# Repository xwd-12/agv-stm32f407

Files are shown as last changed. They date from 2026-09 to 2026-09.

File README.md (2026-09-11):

# STM32F407 AGV 智能搬运机器人

> 2026 全国大学生嵌入式芯片与系统设计竞赛 ST 赛道参赛作品

本项目以 STM32F407ZGTx 为主控，构建四轮差速移动底盘、4-DOF 机械臂、独立挂钩舵机与 OpenMV H7 Plus 视觉系统。它将巡线、二维码触发、端侧视觉识别、颜色对准抓取、AprilTag 视觉伺服和无动力从车拖挂串成一套自主搬运流程。

完整任务链路为：巡线行驶 -> 十字路口触发 -> AprilTag 对接从车 -> QR 触发工位任务 -> 视觉识别与抓取 -> 从车装载或交付。

> 当前默认烧录配置用于工位演示：程序假定从车已预先挂接，并从巡线和工位任务开始执行。完整自动对接功能保留在工程中，需恢复经过实车标定的完整构建配置后再启用。

## 目录

- [功能概览](#功能概览)
- [完整作业流程](#完整作业流程)
- [硬件与软件架构](#硬件与软件架构)
- [视觉任务](#视觉任务)
- [构建与部署](#构建与部署)
- [串口调试](#串口调试)
- [目录结构](#目录结构)
- [安全说明](#安全说明)

## 功能概览

| 能力 | 已实现内容 |
| --- | --- |
| 自主巡线 | 5 路红外巡线、PID 转向、十字路口识别与路线切换 |
| 从车对接 | AprilTag 搜索、视觉伺服倒车、挂钩动作与回归巡线 |
| 视觉搬运 | QR 任务触发、AI 分类、颜色目标对准、抓取与放置 |
| 机械臂控制 | 4-DOF 机械臂动作组、独立挂钩舵机、五次样条平滑运动 |
| 实时控制 | TIM6 100 Hz 控制心跳，巡线、视觉伺服和机械臂状态协同运行 |
| 调试与调参 | UART5 指令调试、OpenMV 数据查看、可选 CSV 遥测与 LLM PID Tuner |

## 完整作业流程

```mermaid
flowchart TD
    A[上电巡线] --> B[十字检测]
    B --> C[AprilTag 对接]
    C --> D[挂接从车]
    D --> E[工位零]
    E --> F[三件抓取]
    F --> G[工位一]
    G --> H[取件交付]
    H --> I[完成停车]
```

完整流程中，车辆先在十字路口进入从车对接阶段，再由 AprilTag 提供相对位姿信息完成视觉引导。挂接后，二维码触发工位任务；系统按红色六边形、黄色长方形、绿色圆形的顺序处理目标，并在两个工位完成装载与交付。

当前 `User/main.c` 的默认配置以工位调试为目的，启用 `SKIP_DOCK=1`，从车应在上电前完成手动挂接。自动对接状态机及其现场参数仍保留在工程内，但当前处于调试禁用状态。复现全流程前应恢复已验证的完整配置、检查场地与标记尺寸，并重新烧录后实车测试；不要仅修改一个宏后直接上车运行。

## 硬件与软件架构

### 硬件组成

| 子系统 | 配置 |
| --- | --- |
| 主控 | STM32F407ZGTx，主频 168 MHz |
| 移动底盘 | 四轮差速底盘，直流减速电机与 PWM 驱动 |
| 机械执行 | 4-DOF 机械臂，腰座、大臂、小臂、夹爪与独立挂钩舵机 |
| 视觉 | OpenMV Cam H7 Plus，支持 QR、AprilTag、颜色识别与端侧分类 |
| 巡线传感 | 5 路红外巡线传感器 |
| 调试通信 | UART5，115200 8N1，USB-TTL 连接 |
| 视觉通信 | USART3，115200，与 OpenMV 专用连接 |

完整引脚映射、外设初始化和中断优先级见 [ARCHITECTURE.md](ARCHITECTURE.md)。

### 软件分层

| 层级 | 主要文件 | 职责 |
| --- | --- | --- |
| 实时控制 | `Timer.c`、`pid.c`、`line_follow.c`、`visual_servo.c` | 100 Hz 控制心跳、巡线 PID、位置/速度控制、视觉伺服 |
| 任务编排 | `main.c`、`state_machine.c`、`vision_task.c` | 从车对接、QR 任务、机械臂状态管理与多步骤任务队列 |
| 视觉通信 | `commend_openmv.c`、`OpenMV_scripts/main.py` | USART3 环形缓冲、视觉数据协议与相机模式切换 |
| 机械执行 | `action_group.c`、`servo.c`、`smooth_servo.c` | 抓取、放置、挂钩及平滑舵机轨迹 |
| 调试接口 | `uart.c`、`command.c` | UART5 命令解析、状态查询与遥测控制 |

系统由 7 个协作状态机组织自主任务，包括机械臂、视觉伺服、视觉任务、任务队列、传统导航、QR 任务流水线和从车对接状态机。

## 视觉任务

OpenMV 在 QR、AprilTag、颜色和 AI 分类模式之间切换，通过 USART3 向主控发送识别结果。二维码负责触发任务，AI 分类确定目标类别，颜色追踪用于末端对准，AprilTag 用于从车对接。

| class_id | 标签 | 颜色目标 |
| :---: | --- | --- |
| 0 | `red_hexagon` | 红色六边形 |
| 1 | `green_circle` | 绿色圆形 |
| 2 | `yellow_rect` | 黄色长方形 |

`OpenMV_scripts/train_mid_f32.py` 可训练并导出当前相机脚本使用的 Float32 MobileNetV2 模型 `model_mid_f32.tflite`。模型文件不随仓库提供；部署时必须使用与 `main.py` 和 `labels.txt` 匹配的模型与标签文件。

## 构建与部署

### STM32 固件

开发环境为 Keil MDK-ARM V5.06 与 ARM Compiler 5。工程使用 C90 语法，新写的局部变量应在代码块开头声明。

1. 打开 `Project/RVMDK（uv5）/SICV_F407.uvprojx`。
2. 选择目标 `AGV`，确认芯片为 STM32F407ZGTx。
3. 按 `F7` 编译。
4. 通过 ST-Link 的 SWD 接口（PA13/PA14）连接开发板，按 `F8` 下载。
5. 编译产物位于 `Output/LED.axf` 和 `Output/LED.hex`。

`keilkill.bat` 会清理构建产物；运行后必须重新执行 `F7`，再执行 `F8` 下载。新增 `User/` 下的 `.c` 或 `.h` 文件后，还需要在 Keil 的 Project Items 中手动加入工程。

### OpenMV 部署

1. 通过 USB 连接 OpenMV H7 Plus。Windows 下通常会挂载为 `H:` 盘。
2. 将 `OpenMV_scripts/main.py`、`OpenMV_scripts/labels.txt` 和匹配的 `model_mid_f32.tflite` 复制到相机内部 Flash 根目录。
3. 相机启动后默认进入 QR 模式；STM32 会根据任务切换 QR、AI、COLOR 或 APRILTAG 模式。

若需要重新训练模型，请在具备 TensorFlow 环境的电脑中进入 `OpenMV_scripts/`，运行 `train_mid_f32.py`，再将导出的模型和标签部署到相机。

### PID Tuner（可选）

配套调参工具位于 `llm-pid-tuner-dev/`。先将根目录的 `config.example.json` 复制为 `config.json`，填入自己的接口配置；真实配置文件已被 Git 忽略，不应提交到仓库。具体运行方式见 [llm-pid-tuner-dev/README.md](llm-pid-tuner-dev/README.md)。

## 串口调试

调试串口为 UART5（PC12/PD2，115200 8N1）。启动后的前 3 秒内，命令会执行但不回显，用于抑制 USB-TTL 上电噪声。

| 命令 | 用途 |
| --- | --- |
| `help` | 查看完整命令列表 |
| `run` / `restart` | 重置自主任务流程并返回巡线 |
| `flow` | 查看整条任务链路的当前状态 |
| `crossdock <0|1>` | 开关十字路口自动对接触发 |
| `dockstat` | 查看从车对接状态 |
| `vpid` | 查看视觉伺服参数与对准状态 |
| `vmode <mode>` | 切换 OpenMV 视觉模式 |
| `vdata` / `vcls` | 查看最新视觉目标或分类结果 |
| `mode <0|1|2|3>` | 切换手动、巡线、位置或视觉伺服模式 |
| `stop` | 紧急停车并切换为手动模式 |

## 目录结构

```text
.
├── User/                         # STM32 应用层源码
│   ├── main.c                    # 主循环、任务流程与对接编排
│   ├── line_follow.c/h           # 巡线控制
│   ├── visual_servo.c/h          # AprilTag 视觉伺服
│   ├── state_machine.c/h         # 机械臂与任务状态机
│   ├── command.c/h               # 串口命令解析
│   └── commend_openmv.c/h        # OpenMV 通信协议
├── OpenMV_scripts/               # 相机脚本、训练脚本、标签与数据集
├── Project/RVMDK（uv5）/          # Keil 工程
├── Libraries/                    # CMSIS 与 STM32 标准外设库
├── llm-pid-tuner-dev/            # 可选 PID 自动调参工具
├── Output/                       # Keil 构建产物
├── ARCHITECTURE.md                # 完整硬件与软件架构参考
└── READY.md                       # 实机调试记录与待办
```

## 安全说明

- 首次烧录或更改运动、视觉、机械臂参数后，应先将车辆架空或在可控场地单独验证，再进行整流程演示。
- `stop`、低压制动、机械臂动作超时和视觉目标丢失保护用于降低风险，但不能替代现场监护。
- 公开仓库仅提供 `config.example.json`；请自行创建本地 `config.json`，并妥善保管 API Key、设备端模型和本机串口配置。

## 参考文档

- [ARCHITECTURE.md](ARCHITECTURE.md)：硬件引脚、控制链路、通信协议和状态机细节。
- [READY.md](READY.md)：实机调试记录、从车对接参数和后续计划。
- [llm-pid-tuner-dev/README.md](llm-pid-tuner-dev/README.md)：PID Tuner 的安装与使用说明。

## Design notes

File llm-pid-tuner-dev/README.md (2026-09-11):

# LLM-PID-Tuner

一个用大语言模型辅助 PID 调参的实用工具。

> 💬 QQ 1群：1082281492 - 欢迎加入交流讨论
> 📺 [B站教程视频](https://b23.tv/WVUuIFb) - 详细视频教程手把手教你使用
> 📺 [YouTube 教程视频](https://youtu.be/Giruc9kN53Y)

中文 | [English](https://github.com/KINGSTON-115/llm-pid-tuner/blob/dev/docs/en-US/README.md)

Star History Chart (https://star-history.com/#KINGSTON-115/llm-pid-tuner)

> 如果你是第一次接触这个项目，**不要先折腾 Python**。
> **最省事的用法是直接下载 Release 里的 `llm-pid-tuner.exe`。**

## 最新开发版教程入口

如果你想看 **最新功能、最新教程、最新 Simulink 配置说明**，请直接参考 `dev` 分支文档：

- [最新总览（中文）](https://github.com/KINGSTON-115/llm-pid-tuner/blob/dev/README.md) | [最新总览（ENGLISH）](https://github.com/KINGSTON-115/llm-pid-tuner/blob/dev/docs/en-US/README.md)
- [最新 Simulink 指南（中文）](https://github.com/KINGSTON-115/llm-pid-tuner/blob/dev/docs/zh-CN/MATLAB_GUIDE.md) | [最新 Simulink 指南（ENGLISH）](https://github.com/KINGSTON-115/llm-pid-tuner/blob/dev/docs/en-US/MATLAB_GUIDE.md)
- [最新项目说明（中文）](https://github.com/KINGSTON-115/llm-pid-tuner/blob/dev/docs/zh-CN/PROJECT_DOC.md) | [最新项目说明（ENGLISH）](https://github.com/KINGSTON-115/llm-pid-tuner/blob/dev/docs/en-US/PROJECT_DOC.md)

如果你只想使用 **当前稳定版 main**，继续阅读本页即可。

## 目录

- [系统结构图](#系统结构图)
- [先看你该怎么用](#先看你该怎么用)
- [这个项目适合什么场景](#这个项目适合什么场景)
- [它不是做什么的](#它不是做什么的)
- [3 分钟上手：Windows 打包版（推荐给小白）](#3-分钟上手windows-打包版推荐给小白)
- [config.json 怎么填](#configjson-怎么填)
- [推荐模型与接口填写方式](#推荐模型与接口填写方式)
- [如何自定义提示词 (Prompt)](#如何自定义提示词-prompt)
- [MATLAB/Simulink 仿真模式](#matlabsimulink-仿真模式)
- [如果你还没有硬件，先跑仿真](#如果你还没有硬件先跑仿真)
- [进阶：源码方式运行](#进阶源码方式运行)

## 系统结构图

```text
┌──────────────────────── 本地仿真模式 (Simulator) ────────────────────────┐
│                                                                         │
│  simulator.py  ───────────── API(JSON) ─────────────>  LLM / AI Tuner   │
│  (热系统仿真)                                           (生成 PID 建议)   │
│                                                                         │
└─────────────────────────────────────────────────────────────────────────┘

┌──────────────────────── 真实硬件模式 (Hardware) ─────────────────────────┐
│                                                                         │
│  MCU / firmware.cpp ── Serial(CSV) ──> tuner.py ── API ──> LLM          │
│  (Arduino / ESP32)                    (上位机 / .exe)                    │
│                                                                         │
└─────────────────────────────────────────────────────────────────────────┘
```

## 先看你该怎么用

- **只想调硬件，不想配开发环境**：走 `exe` 路线，见下方“3 分钟上手”。
- **想先看看这个项目到底有没有用**：运行 `simulator.py` 做本地热系统仿真。
- **想接自己的 Arduino / ESP32 / 其他控制板**：使用 `firmware.cpp` + `tuner.py` / `llm-pid-tuner.exe`。
- **想二次开发或看内部设计**：看 [PROJECT_DOC.md](docs/zh-CN/PROJECT_DOC.md)。

## 这个项目适合什么场景

- 恒温控制：加热板、热端、恒温箱、水浴、烘箱
- 电机 / 执行器：需要 PID 闭环调节的对象
- 已经能跑，但参数不好：响应慢、超调大、抖动、稳态误差明显
- 没有成熟整定经验，希望让 LLM 先帮你缩小试错范围

## 它不是做什么的

- 它**不是**“一键保证完美控制”的魔法程序
- 它**不是**替代硬件保护的安全系统
- 它**不是**为了漂亮 benchmark 分数而设计的玩具

这个项目更在意的是：**真实调参时少走弯路、少炸参数、调差了还能回退。**

---

## 3 分钟上手：Windows 打包版（推荐给小白）

### 第 1 步：下载打包版

打开 [Release](https://github.com/KINGSTON-115/llm-pid-tuner/releases/latest) 页面，并下载资产里的 `llm-pid-tuner.exe`。

### 第 2 步：准备硬件

你需要一个能通过串口持续上报控制数据的板子。

最简单的方式是直接参考仓库里的 `firmware.cpp`，它已经实现了这个项目默认使用的串口协议。

程序默认希望设备通过串口持续输出类似下面的 CSV 数据：

```text
timestamp_ms,setpoint,input,pwm,error,p,i,d
```

如果你不想自己适配协议，**最省事的办法就是直接从 `firmware.cpp` 开始。**

如果你要对接这些已知协议格式，可以在 `config.json` 里明确指定 `HARDWARE_PROFILE`：

- `generic_serial_csv`：默认 CSV 串口数据，适合 `firmware.cpp` 和演示模式
- `stm32f407_openmv`：STM32F407 + OpenMV 瞄准链路，支持 `Status:` 文本、`T:x,y` 和 `N`
- `mspm0_datavision`：MSPM0 DataVision 采样链路，当前是只读遥测模式，不向硬件写回 PID 参数

### 第 3 步：第一次运行 exe

双击运行 `llm-pid-tuner.exe`。

启动器会先让你选择模式：`[1]` 真实硬件调参，`[2]` 本地仿真 TUI（默认）。
如果你现在是准备接串口硬件，请先选 `[1]`。

第一次运行时，如果当前目录下没有 `config.json`，程序会自动生成一份默认配置。

### 第 4 步：填写 `config.json`

打开 `config.json`，至少先把“硬件模式最小必填项”改掉：

```json
{
  "SERIAL_PORT": "AUTO",
  "BAUD_RATE": 115200,
  "HARDWARE_PROFILE": "generic_serial_csv",
  "LLM_API_KEY": "sk-your-key",
  "LLM_API_BASE_URL": "https://api.openai.com/v1",
  "LLM_MODEL_NAME": "gpt-4o",
  "LLM_PROVIDER": "openai"
}
```

如果你只是想先跑 `simulator.py` 看效果，没有接真实串口，也可以先不填 `SERIAL_PORT`，只把 LLM 相关字段填好。

如果你要用 **MiniMax / DeepSeek / Ollama / LM Studio** 这类 OpenAI 兼容接口，通常这样配就行：

```json
{
  "LLM_API_KEY": "你的 key",
  "LLM_API_BASE_URL": "你的 /v1 地址",
  "LLM_MODEL_NAME": "你的模型名",
  "LLM_PROVIDER": "openai"
}
```

比如 MiniMax 兼容接口可以是：

```json
{
  "LLM_API_BASE_URL": "http://你的地址/v1",
  "LLM_MODEL_NAME": "MiniMax-M2.5",
  "LLM_PROVIDER": "openai"
}
```

如果你用的是 **Claude 中转站 / OneAPI / New API 这类 OpenAI 兼容接口**，现在也可以更明确地写成：

```json
{
  "LLM_API_BASE_URL": "https://你的中转站/v1",
  "LLM_MODEL_NAME": "claude-3-7-sonnet",
  "LLM_PROVIDER": "openai_claude"
}
```

`openai_claude` 和 `openai` 都会走 OpenAI 兼容协议；前者只是专门给 Claude 中转站准备的显式选项。

如果你使用 Claude 原生接口，再把 `LLM_PROVIDER` 改成 `anthropic`。

### 第 5 步：重新运行 exe

保存 `config.json` 后重新运行程序。

- 如果 `SERIAL_PORT` 填的是 `AUTO`，程序会扫描串口并让你选择
- 如果你已经知道端口号，比如 `COM5`，也可以直接写死，省掉选择步骤

### 第 6 步：观察调参结果

程序会持续：

- 读取串口数据
- 分析当前响应质量
- 请求 LLM 给出新的 PID 建议
- 必要时使用保底策略
- 如果后续结果变差，会回退到之前更稳的参数
- 当系统“已经够好”时，会尽量提前停止，避免过调

当一轮评测同时满足 `GOOD_ENOUGH_AVG_ERROR`、`GOOD_ENOUGH_STEADY_STATE_ERROR` 和 `GOOD_ENOUGH_OVERSHOOT` 时，程序会保持当前 PID 参数进入观察轮，而不是继续请求 LLM 改参数。连续 `REQUIRED_STABLE_ROUNDS` 轮评测都稳定后停止，默认是 3 轮；如果观察过程中响应变差，稳定计数会清零并恢复正常调参。

你最终需要做的事通常只有一件：**把收敛后的 PID 参数写回你的固件。**

---

## `config.json` 怎么填

第一次运行 `tuner.py`、`simulator.py` 或 `llm-pid-tuner.exe` 时，如果当前目录没有 `config.json`，程序会自动生成一份默认配置。

如果你喜欢先看模板，也可以直接参考仓库里的 `config.example.json`。

### 先改这些就能跑起来

**1. 真实硬件模式最小必填**

```json
{
  "SERIAL_PORT": "AUTO",
  "BAUD_RATE": 115200,
  "HARDWARE_PROFILE": "generic_serial_csv",
  "LLM_API_KEY": "sk-your-key",
  "LLM_API_BASE_URL": "https://api.openai.com/v1",
  "LLM_MODEL_NAME": "gpt-4o",
  "LLM_PROVIDER": "openai"
}
```

**2. 本地 Python 仿真最小必填**

```json
{
  "LLM_API_KEY": "sk-your-key",
  "LLM_API_BASE_URL": "https://api.openai.com/v1",
  "LLM_MODEL_NAME": "gpt-4o",
  "LLM_PROVIDER": "openai"
}
```

**3. Simulink 模式额外补这几项**

```json
{
  "MATLAB_MODEL_PATH": "C:/models/my_pid_model.slx",
  "MATLAB_PID_BLOCK_PATH": "my_pid_model/PID Controller",
  "MATLAB_ROOT": "D:/Program Files/MATLAB/R2025b",
  "MATLAB_OUTPUT_SIGNAL": "y_out",
  "MATLAB_SIM_STEP_TIME": 15.0,
  "MATLAB_SETPOINT": 200.0
}
```

这 6 项是跑通单控制器模型的**最小必填**。

如果你的 Simulink 模型不是“单个标准 PID Controller 块 + 一个输出信号”这种最简单结构（例如主副环、分离式 P/I/D 增益块），程序也支持更复杂的兼容字段。

> **请直接查看完整的 [MATLAB/Simulink 调参指南](docs/zh-CN/MATLAB_GUIDE.md)**。
> 指南里详细说明了：
> - 如何快速获取正确的 Simulink 块路径
> - 如何配置双控制器与分离式增益块
> - `MATLAB_ROOT` 什么时候可以不填
> - 常见环境报错（如 `No module named matlab.engine`）的解决方法

### 按场景看配置项

| 分类 | 什么时候需要 | 字段 | 说明 |
| :--- | :--- | :--- | :--- |
| 硬件串口 | 真实硬件调参 | `SERIAL_PORT` `BAUD_RATE` `HARDWARE_PROFILE` | `SERIAL_PORT` 不确定先填 `AUTO`，`BAUD_RATE` 要和固件一致；普通 CSV 固件保持 `HARDWARE_PROFILE=generic_serial_csv` |
| LLM 基础 | 所有模式都需要 | `LLM_API_KEY` `LLM_API_BASE_URL` `LLM_MODEL_NAME` `LLM_PROVIDER` | 这是最核心的一组配置，不填就无法调参 |
| 调参行为 | 想微调策略时再改 | `BUFFER_SIZE` `MIN_ERROR_THRESHOLD` `MAX_TUNING_ROUNDS` `LLM_REQUEST_TIMEOUT` `LLM_DEBUG_OUTPUT` `PID_LIMITS` `PID_MAX_INCREASE_RATIO` `GOOD_ENOUGH_AVG_ERROR` `GOOD_ENOUGH_STEADY_STATE_ERROR` `GOOD_ENOUGH_OVERSHOOT` `REQUIRED_STABLE_ROUNDS` | 新手建议先保持默认，只有在采样不够、网络慢或需要排查日志时再动。`PID_LIMITS` 用于配置 P/I/D 的绝对上下限和默认单轮增幅；程序会把实际限幅写入 LLM 提示词，并在下发前强制执行。`PID_MAX_INCREASE_RATIO` 是额外的全局单轮增幅上限；`GOOD_ENOUGH_*` 定义“已经够好”的阈值；`REQUIRED_STABLE_ROUNDS` 是连续稳定轮数，默认 3 轮。 |
| Simulink | 只在 MATLAB/Simulink 模式下需要 | `MATLAB_MODEL_PATH` `MATLAB_PID_BLOCK_PATH` `MATLAB_ROOT` `MATLAB_OUTPUT_SIGNAL` `MATLAB_SIM_STEP_TIME` `MATLAB_SETPOINT`，以及按需填写 `MATLAB_CONTROL_SIGNAL` `MATLAB_SETPOINT_BLOCK` `MATLAB_PID_BLOCK_PATHS` `MATLAB_PID_BLOCK_PATH_2` `MATLAB_P/I/D_BLOCK_PATH(_2)` | 最小 6 项先跑通，复杂模型再逐步补充兼容字段 |
| 代理 | 只有需要代理时才填 | `HTTP_PROXY` `HTTPS_PROXY` `ALL_PROXY` `NO_PROXY` | 留空就是不启用 |

> 硬件模式还带有内建的采样保护阈值（采样超时与最少有效样本数）。这些属于固定安全策略，目前不作为 `config.json` 的用户配置项开放。

### `MATLAB_ROOT` 什么时候要填

见 [MATLAB/Simulink 调参指南](docs/zh-CN/MATLAB_GUIDE.md)。

### 关于环境变量

程序也支持环境变量，并且**环境变量优先级高于 `config.json`**。

例如：

```powershell
$env:LLM_API_KEY="sk-xxx"
$env:LLM_API_BASE_URL="http://127.0.0.1:11434/v1"
$env:LLM_MODEL_NAME="qwen2.5:7b"
$env:LLM_PROVIDER="openai"
```

如果你是小白，**优先用 `config.json`，更直观。**

### 关于代理（可选）

如果你需要走 VPN/代理，可以在 `config.json` 里新增以下字段：

```json
{
  "HTTP_PROXY": "http://127.0.0.1:7890",
  "HTTPS_PROXY": "http://127.0.0.1:7890",
  "ALL_PROXY": "http://127.0.0.1:7890",
  "NO_PROXY": ""
}
```

留空则**不启用代理**，对不需要代理的用户没有影响。

### 导出 CSV 数据（可选）

如果你希望将调参过程中的实时数据（时间戳、设定值、当前值、PWM、误差、PID参数等）保存下来，以便后续在 Excel 或 MATLAB 中分析，可以在 `config.json` 中配置 `CSV_EXPORT_PATH` 字段：

```json
{
  "CSV_EXPORT_PATH": "logs/tuning_data.csv"
}
```

- 填入你希望保存的 CSV 文件路径（支持相对路径或绝对路径）。
- 每次运行调参时，程序会自动将数据追加到该文件中，并记录当前的 `session_id` 和 `round`（轮次），方便你区分不同次的调参记录。
- 留空（`""`）则**不导出 CSV**。

---

## 推荐模型与接口填写方式

| 方案 | `LLM_API_BASE_URL` 示例 | `LLM_PROVIDER`  | 说明 |
| :--- | :--- | :--- | :--- |
| OpenAI | `https://api.openai.com/v1` | `openai` | 最省心 |
| DeepSeek 兼容接口 | 对应服务商的 `/v1` 地址 | `openai` | 常见且便宜 |
| MiniMax 兼容接口 | 对应服务商的 `/v1` 地址 | `openai` | 推理能力适合调参 |
| Claude 中转站 / OneAPI / New API | 对应服务商的 `/v1` 地址 | `openai_claude` | Claude 模型走 OpenAI 兼容协议时用这个最直观 |
| Ollama | `http://localhost:11434/v1` | `openai` | 本地免费部署 |
| LM Studio | `http://localhost:1234/v1`  | `openai` | 本地可视化较友好 |
| Anthropic Claude | `https://api.anthropic.com` | `anthropic` | 原生接口用这个 |

这个项目现在做了更稳的解析和回退处理，**对 OpenAI 兼容接口更友好**。如果 SDK 路径不顺，它也会尽量走更直接的 HTTP 路径，减少“能调通 API 但程序不工作”的情况。

---

## 如何自定义提示词 (Prompt)

本项目提供了两种自定义提示词（调参策略）的方式，以适应不同的需求：

### 1. 预调参对话（推荐，无需改代码）
在每次启动调参（无论是仿真还是硬件模式）时，程序会首先进入**预调参对话 (Pre-Tuning Conversation)**。
在这里，你可以直接用自然语言输入你的偏好。例如：
- *"我希望系统绝对稳定，不能有任何超调，哪怕响应慢一点也没关系。"*
- *"这是一个对响应速度要求极高的系统，允许 10% 以内的超调，请尽可能激进地调参。"*
- *"注意，这个电机的死区比较大，P 参数可以给大一点。"*

程序会自动将你的自然语言偏好转化为结构化的 JSON 约束，并附加到 LLM 的系统提示词中，从而改变 LLM 的调参行为。

### 2. 修改源码中的系统提示词（进阶）
如果你希望永久改变 LLM 的核心调参逻辑或角色设定，你需要修改源码：
1. 打开 `llm/prompts.py` 文件。
2. 找到 `_BASE_SYSTEM_PROMPT` 变量，这里定义了 LLM 的核心角色、职责和调参原则。
3. 找到 `_MODE_NOTES` 变量，这里定义了不同模式（如 `hardware`, `simulink`, `python_sim`）下的特定规则。
4. 根据你的需求修改这些字符串内容即可。

---

## MATLAB/Simulink 仿真模式

如果你已经有 MATLAB/Simulink 仿真模型，可以直接让 LLM 对你的模型进行 PID 调参，无需真实硬件。

在 `config.json` 里至少填写下面这些字段，再运行 `python simulator.py` 或打包版启动器里的 Simulink 模式：

- `MATLAB_MODEL_PATH`：Simulink `.slx` 文件路径
- `MATLAB_PID_BLOCK_PATH`：模型里的 PID 模块完整路径
- `MATLAB_OUTPUT_SIGNAL`：To Workspace 输出变量名
- `MATLAB_ROOT`：MATLAB 安装根目录；打包版建议填写，源码运行如果当前 Python 已装好 MATLAB Engine 可以留空

详细配置步骤、模型准备方法和常见问题，见 [MATLAB/Simulink 调参指南](docs/zh-CN/MATLAB_GUIDE.md)。

---

## 如果你还没有硬件，先跑仿真

如果你只是想确认这个项目到底在干什么，先跑这个：

```bash
pip install -r requirements.txt
python simulator.py
```

`simulator.py` 会在本地模拟一个热系统，然后让 LLM 自动调参。
这条路线最适合先理解项目，而不是直接上真实硬件。

在调参循环开始前，程序现在会自动进行两个对新手非常友好的操作：
- 运行环境诊断（`doctor.py`），检查配置、API 连接性、串口及代理设置。
- 进行简短的系统辨识（热启动），给出比默认值更合理的初始 PID 建议。

此外，交互模式下支持**预调参对话**（Pre-Tuning Dialog）。你可以用自然语言直接输入调参偏好或限制（例如：“超调不能超过 5%” 或 “响应可以慢点但绝不能震荡”），LLM 会自动提取为调参的硬性约束。

如果你只想手动运行环境检查而不启动仿真，可以使用：

```bash
python doctor.py
```

---

## 进阶：源码方式运行

如果你不想用 exe，也可以直接跑源码。

### 分支说明（重要）

- `dev` 分支：当前最新开发代码，功能修复、TUI 改动、打包前验证都会先进入这里
- `main` 分支：更偏稳定展示和正式 release，同步会慢一些，不保证是当前最新行为
- 如果你想源码运行、跟进最近修复，或者准备提 PR，建议直接拉 `dev`

### 新拉仓库：直接拉 `dev`

```bash
git clone -b dev https://github.com/KINGSTON-115/llm-pid-tuner.git
cd llm-pid-tuner
```

### 你已经拉过仓库：切到 `dev` 并更新

```bash
git fetch origin
git checkout dev
git pull --ff-only origin dev
```

### 安装依赖

```bash
pip install -r requirements.txt
```

如果你要跑 Simulink 源码模式，还需要让当前这个 Python 环境能导入 `matlab.engine`。不会配的话，直接看 [MATLAB/Simulink 调参指南](docs/zh-CN/MATLAB_GUIDE.md)。

### 运行前先确认配置

- 跑 `python tuner.py`：至少填好 LLM 配置和串口配置
- 跑 `python simulator.py`：至少填好 LLM 配置
- 跑 Simulink：再额外补 `MATLAB_*` 相关字段

第一次运行时如果没有 `config.json`，程序会自动生成一份默认配置；你也可以直接从 `config.example.json` 开始改。

### 运行仿真

```bash
python simulator.py
```

如果你想用旧式纯日志输出，而不是 TUI，或者需要强制切换显示语言：

```bash
python simulator.py --plain
python simulator.py --lang en  # 强制使用英文界面，默认支持根据系统自动检测语言
```

### 连接真实硬件

```bash
python tuner.py
```

### 做系统辨识（可选）

你可以先采一段阶跃响应数据，再用 `system_id.py` 给出一组初值建议：

```bash
python system_id.py --file sample_step.csv
```

这适合想先拿到一组“不会太离谱”的初始参数，再交给 LLM 继续细调的用户。

---

## 主要文件是干什么的

| 文件 | 用途 |
| :--- | :--- |
| `launcher.py` | 启动器，可选择硬件或仿真模式并支持语言切换 |
| `tuner.py` | 真实硬件调参主程序，也是 exe 的核心入口 |
| `simulator.py` | 本地热系统仿真，适合演示和验证策略 |
| `pid_safety.py` | 参数保护、保底策略、最佳结果记录、回退逻辑 |
| `firmware.cpp` | 单片机侧示例固件，负责串口上报与执行 PID |
| `system_id.py` | 利用阶跃响应做系统辨识，给出初始 PID 建议  |
| `doctor.py` | 环境诊断检查工具，快速排查配置与连接问题 |
| `benchmark.py` | 固定随机种子的对比工具，更偏开发验证用途 |
| `config.json` | 运行配置文件 |
| `docs/zh-CN/PROJECT_DOC.md` | 面向开发者的内部说明文档 |

---

## 常见问题

### 1）双击 exe 后一闪而过

常见原因：

- `config.json` 还没填好
- API Key 无效
- 串口打不开
- 当前目录没有写入权限，导致配置文件生成失败

建议直接在 PowerShell 里运行，这样错误信息不会消失：

```powershell
.\llm-pid-tuner.exe
```

### 2）程序找不到串口

检查下面几件事：

- 设备是否真的连上电脑
- 驱动是否安装正确
- 其他上位机是否已经占用了串口
- `BAUD_RATE` 是否和单片机一致

### 3）程序连上了，但一直没有数据

大概率是你的固件输出格式和项目默认协议不一致。
最稳妥的办法是先按 `firmware.cpp` 的格式对齐。

### 4）LLM 能聊天，但程序调不动

多数时候是这几类问题：

- `LLM_API_BASE_URL` 写错
- 模型名写错
- 你用的是 OpenAI 兼容接口，但 `LLM_PROVIDER` 填成了 `anthropic`
- 你用的是 Claude 中转站，但把它当成了 Anthropic 原生接口；这时应该用 `openai_claude` 或 `openai`
- 服务端虽然可用，但返回 JSON 风格不稳定

### 5）调着调着结果变差怎么办

现在的程序会：

- 给 PID 做基本护栏限制
- LLM 异常时启用保底建议
- 记录历史最佳稳定参数
- 后续结果明显变差时自动回退

也就是说，它的设计目标不是“每一轮都更激进”，而是**优先把系统留在一个更稳、更可用的位置。**

### 6）能不能完全离线使用

可以，但前提是你本地起了兼容 OpenAI 接口的模型服务，比如：

- Ollama
- LM Studio

然后把 `LLM_API_BASE_URL` 指向本地地址即可。

---

## 安全提醒

**在真实硬件上调参时，请务必有人值守。**

尤其是加热类系统，一定要有：

- 硬件级限温
- 传感器异常保护
- 继电器 / MOS 管失控保护
- 必要时的物理断电手段

这个项目能帮你减少调参痛苦，但**不能替代硬件安全设计**。

---

## 补充说明

- 最新打包版请看 [Release](https://github.com/KINGSTON-115/llm-pid-tuner/releases/latest)
- 打包方法见 [Issue #11](https://github.com/KINGSTON-115/llm-pid-tuner/issues/11)
- 当前 Windows 打包使用 Python `3.10` 环境（本项目测试使用 `matlab310` conda 环境），`llm-pid-tuner.spec` 会从当前环境收集必要 DLL
- 历史测试环境包含 `R2022b`；文档里的 `R2025b` 只是示例路径版本，请替换成你本机实际安装的 MATLAB 版本
- 想看项目内部设计，请看 [PROJECT_DOC.md](docs/zh-CN/PROJECT_DOC.md)

## License

`CC BY-NC-SA 4.0`

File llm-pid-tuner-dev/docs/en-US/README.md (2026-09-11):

# LLM-PID-Tuner

An LLM-assisted PID tuning tool focused on reducing the painful trial-and-error process of real controller tuning.

[中文](../../README.md) | English

Star History Chart (https://star-history.com/#KINGSTON-115/llm-pid-tuner)

> 📺 [Video Tutorial (Bilibili)](https://b23.tv/WVUuIFb)
> 📺 [YouTube Tutorial](https://youtu.be/Giruc9kN53Y)

> New here? The easiest path is **not** Python.
> Download the packaged `llm-pid-tuner.exe` from Releases and start there.

## Table of Contents

- [System Architecture](#system-architecture)
- [Best starting path](#best-starting-path)
- [3-minute quick start for beginners](#3-minute-quick-start-for-beginners)
- [How to fill config.json](#how-to-fill-configjson)
- [How to customize prompts](#how-to-customize-prompts)
- [MATLAB/Simulink Simulation Mode](#matlabsimulink-simulation-mode)
- [If you don't have hardware yet, run the simulator](#if-you-dont-have-hardware-yet-run-the-simulator)
- [Advanced: Running from source](#advanced-running-from-source)

## System Architecture

```text
┌──────────────────────── Local Simulation Mode ──────────────────────────┐
│                                                                         │
│  simulator.py  ───────────── API(JSON) ─────────────>  LLM / AI Tuner   │
│  (thermal model)                                        (PID decisions) │
│                                                                         │
└─────────────────────────────────────────────────────────────────────────┘

┌──────────────────────── Real Hardware Mode ─────────────────────────────┐
│                                                                         │
│  MCU / firmware.cpp ── Serial(CSV) ──> tuner.py ── API ──> LLM          │
│  (Arduino / ESP32)                    (host app / exe)                  │
│                                                                         │
└─────────────────────────────────────────────────────────────────────────┘
```

## Best starting path

- **Just want to tune hardware**: use the packaged `exe`
- **Want to see the idea first**: run `simulator.py`
- **Want to integrate your own board**: use `firmware.cpp` + `tuner.py`
- **Want internals**: read [PROJECT_DOC.md](PROJECT_DOC.md)

---

## 3-minute quick start for beginners

### 1. Download the packaged app

Open [Latest Release](https://github.com/KINGSTON-115/llm-pid-tuner/releases/latest) page and download `llm-pid-tuner.exe` from the Assets section.

### 2. Prepare hardware

Your board should stream CSV data over serial.

The easiest route is to start from `firmware.cpp`, which already matches the protocol expected by this project.

Expected CSV format:

```text
timestamp_ms,setpoint,input,pwm,error,p,i,d
```

If you use one of the built-in hardware profile adapters, set `HARDWARE_PROFILE` explicitly in `config.json`:

- `generic_serial_csv`: default CSV serial telemetry, suitable for `firmware.cpp` and demo mode
- `stm32f407_openmv`: STM32F407 + OpenMV aiming/targeting telemetry, including `Status:` snapshots, `T:x,y`, and `N`
- `mspm0_datavision`: MSPM0 DataVision telemetry, currently read-only and does not write PID values back to hardware

If you omit this field, the app uses `generic_serial_csv`.

### 3. Run the exe once

Double-click `llm-pid-tuner.exe`.

The launcher now asks which mode to start:
`[1]` hardware tuning or `[2]` the local simulation TUI (default).
If you are connecting a real serial device, choose `[1]`.

If `config.json` does not exist, the program generates a default one automatically.

### 4. Edit `config.json`

At minimum, start with the hardware-mode fields below:

```json
{
  "SERIAL_PORT": "AUTO",
  "BAUD_RATE": 115200,
  "HARDWARE_PROFILE": "generic_serial_csv",
  "LLM_API_KEY": "sk-your-key",
  "LLM_API_BASE_URL": "https://api.openai.com/v1",
  "LLM_MODEL_NAME": "gpt-4o",
  "LLM_PROVIDER": "openai"
}
```

If you only want to try `simulator.py` first and are not connecting real hardware yet, you can leave `SERIAL_PORT` unset and just fill the LLM fields.

For OpenAI-compatible providers such as MiniMax, DeepSeek, Ollama, or LM Studio, keep `LLM_PROVIDER` as `openai` and point `LLM_API_BASE_URL` to the provider's `/v1` endpoint.

Example:

```json
{
  "LLM_API_BASE_URL": "http://your-endpoint/v1",
  "LLM_MODEL_NAME": "MiniMax-M2.5",
  "LLM_PROVIDER": "openai"
}
```

If you use Claude through an OpenAI-compatible relay such as OneAPI or New API, you can now make that explicit:

```json
{
  "LLM_API_BASE_URL": "https://your-relay.example.com/v1",
  "LLM_MODEL_NAME": "claude-3-7-sonnet",
  "LLM_PROVIDER": "openai_claude"
}
```

Both `openai` and `openai_claude` use the OpenAI-compatible transport. `openai_claude` is just the clearer choice for Claude relays.

For native Claude APIs, use `LLM_PROVIDER: "anthropic"`.

### 5. Run it again

- If `SERIAL_PORT` is `AUTO`, the app scans ports and lets you choose
- If you already know the port, set something like `COM5`

### 6. Watch the tuning loop

The app will:

- collect serial data
- evaluate response quality
- ask the LLM for new PID values
- fall back to safer suggestions when needed
- remember the best stable result
- roll back when a later suggestion clearly makes things worse
- stop early when the system is already “good enough”

When one evaluation round satisfies `GOOD_ENOUGH_AVG_ERROR`, `GOOD_ENOUGH_STEADY_STATE_ERROR`, and `GOOD_ENOUGH_OVERSHOOT`, the app keeps the current PID values and enters observation rounds instead of asking the LLM for another adjustment. It stops after `REQUIRED_STABLE_ROUNDS` consecutive stable evaluations, which defaults to 3; if the response gets worse during observation, the stable counter resets and normal LLM tuning resumes.

In practice, this means the tool tries to be useful on real hardware, not just aggressive.

---

## How to fill `config.json`

On the first run of `tuner.py`, `simulator.py`, or `llm-pid-tuner.exe`, the app generates a default `config.json` automatically if one does not exist.

If you prefer starting from a template, check `config.example.json`.

### Start with these fields

**1. Minimum config for real hardware**

```json
{
  "SERIAL_PORT": "AUTO",
  "BAUD_RATE": 115200,
  "HARDWARE_PROFILE": "generic_serial_csv",
  "LLM_API_KEY": "sk-your-key",
  "LLM_API_BASE_URL": "https://api.openai.com/v1",
  "LLM_MODEL_NAME": "gpt-4o",
  "LLM_PROVIDER": "openai"
}
```

**2. Minimum config for the built-in Python simulator**

```json
{
  "LLM_API_KEY": "sk-your-key",
  "LLM_API_BASE_URL": "https://api.openai.com/v1",
  "LLM_MODEL_NAME": "gpt-4o",
  "LLM_PROVIDER": "openai"
}
```

**3. Extra fields for Simulink mode**

```json
{
  "MATLAB_MODEL_PATH": "C:/models/my_pid_model.slx",
  "MATLAB_PID_BLOCK_PATH": "my_pid_model/PID Controller",
  "MATLAB_ROOT": "D:/Program Files/MATLAB/R2025b",
  "MATLAB_OUTPUT_SIGNAL": "y_out",
  "MATLAB_SIM_STEP_TIME": 15.0,
  "MATLAB_SETPOINT": 200.0
}
```

Those six fields are the **minimum setup** for a single-controller model.

If your Simulink model is not the simplest "single standard PID Controller block + one output signal" layout (e.g., dual-loop, split P/I/D gain blocks), the tool also supports advanced compatibility fields.

> **Please refer directly to the full [MATLAB/Simulink Tuning Guide](docs/en-US/MATLAB_GUIDE.md)**.
> The guide covers:
> - How to find exact Simulink block paths easily
> - How to configure dual controllers and split gain blocks
> - When `MATLAB_ROOT` is actually required
> - How to troubleshoot environment errors (e.g., `No module named matlab.engine`)

### Config groups by use case

| Group | When needed | Fields | Notes |
| :---- | :--- | :----- | :---- |
| Serial hardware | Real hardware tuning | `SERIAL_PORT` `BAUD_RATE` `HARDWARE_PROFILE` | Start with `SERIAL_PORT: "AUTO"` and match the firmware baud rate. Keep `HARDWARE_PROFILE=generic_serial_csv` for regular CSV firmware |
| LLM basics | Required in every mode | `LLM_API_KEY` `LLM_API_BASE_URL` `LLM_MODEL_NAME` `LLM_PROVIDER` | This is the core set needed for any tuning run |
| Tuning behavior | Optional | `BUFFER_SIZE` `MIN_ERROR_THRESHOLD` `MAX_TUNING_ROUNDS` `LLM_REQUEST_TIMEOUT` `LLM_DEBUG_OUTPUT` `PID_LIMITS` `PID_MAX_INCREASE_RATIO` `GOOD_ENOUGH_AVG_ERROR` `GOOD_ENOUGH_STEADY_STATE_ERROR` `GOOD_ENOUGH_OVERSHOOT` `REQUIRED_STABLE_ROUNDS` | Leave defaults unless you are tuning strategy or debugging. `PID_LIMITS` configures absolute P/I/D bounds and default per-round increase ratios; the app injects the active limits into the LLM prompt and enforces them before write-back. `PID_MAX_INCREASE_RATIO` is an extra global cap for one adjustment. `GOOD_ENOUGH_*` defines the "good enough" thresholds, and `REQUIRED_STABLE_ROUNDS` is the number of consecutive stable evaluations before stopping. The default is 3. |
| Simulink | MATLAB/Simulink mode only | `MATLAB_MODEL_PATH` `MATLAB_PID_BLOCK_PATH` `MATLAB_ROOT` `MATLAB_OUTPUT_SIGNAL` `MATLAB_SIM_STEP_TIME` `MATLAB_SETPOINT`, plus optional `MATLAB_CONTROL_SIGNAL` `MATLAB_SETPOINT_BLOCK` `MATLAB_PID_BLOCK_PATHS` `MATLAB_PID_BLOCK_PATH_2` `MATLAB_P/I/D_BLOCK_PATH(_2)` | Start with the minimum six fields, then add compatibility fields only when needed |
| Proxy | Only if you need one | `HTTP_PROXY` `HTTPS_PROXY` `ALL_PROXY` `NO_PROXY` | Leave empty to disable |

> Hardware mode also includes built-in sampling guardrails such as a serial sampling timeout and a minimum valid-sample threshold. These are fixed safety defaults and are not exposed as `config.json` user settings right now.

### When should I fill `MATLAB_ROOT`?

See the [MATLAB/Simulink Tuning Guide](docs/en-US/MATLAB_GUIDE.md).

Environment variables are also supported and override `config.json`, but beginners usually find `config.json` easier.

### Proxy (optional)

If you need a VPN/proxy, add these fields to `config.json`:

```json
{
  "HTTP_PROXY": "http://127.0.0.1:7890",
  "HTTPS_PROXY": "http://127.0.0.1:7890",
  "ALL_PROXY": "http://127.0.0.1:7890",
  "NO_PROXY": ""
}
```

Leave them empty to **disable proxy**. If you do not need a proxy, you can ignore these fields.

### Export CSV Data (optional)

If you want to save real-time data during the tuning process (timestamp, setpoint, input, PWM, error, PID parameters, etc.) for later analysis in Excel or MATLAB, you can configure the `CSV_EXPORT_PATH` field in `config.json`:

```json
{
  "CSV_EXPORT_PATH": "logs/tuning_data.csv"
}
```

- Fill in the path where you want to save the CSV file (supports relative or absolute paths).
- Every time you run the tuner, the program will automatically append data to this file and record the current `session_id` and `round`, making it easy to distinguish between different tuning sessions.
- Leave it empty (`""`) to **disable CSV export**.

---

## Recommended providers

| Provider | `LLM_API_BASE_URL` example  | `LLM_PROVIDER`  |
| :--- | :--- | :--- |
| OpenAI | `https://api.openai.com/v1` | `openai` |
| MiniMax-compatible | provider `/v1` URL | `openai` |
| DeepSeek-compatible | provider `/v1` URL | `openai` |
| Claude relay / OneAPI / New API | provider `/v1` URL | `openai_claude` |
| Ollama | `http://localhost:11434/v1` | `openai` |
| LM Studio | `http://localhost:1234/v1`  | `openai` |
| Anthropic Claude | `https://api.anthropic.com` | `anthropic` |

The current runtime is hardened for OpenAI-compatible endpoints and includes a more direct HTTP fallback path when SDK behavior is not enough.

---

## How to customize prompts

This project provides two ways to customize prompts (tuning strategies) to suit different needs:

### 1. Pre-Tuning Conversation (Recommended, no coding required)
Every time you start tuning (whether in simulation or hardware mode), the program will first enter the **Pre-Tuning Conversation**.
Here, you can directly input your preferences in natural language. For example:
- *"I want the system to be absolutely stable with zero overshoot, even if the response is a bit slow."*
- *"This is a system that requires extremely fast response. Overshoot within 10% is acceptable. Please tune as aggressively as possible."*
- *"Note that this motor has a large deadband, so the P parameter can be larger."*

The program will automatically convert your natural language preferences into structured JSON constraints and append them to the LLM's system prompt, thereby changing the LLM's tuning behavior.

### 2. Modify the system prompt in source code (Advanced)
If you want to permanently change the core tuning logic or role setting of the LLM, you need to modify the source code:
1. Open the `llm/prompts.py` file.
2. Find the `_BASE_SYSTEM_PROMPT` variable, which defines the core role, responsibilities, and tuning principles of the LLM.
3. Find the `_MODE_NOTES` variable, which defines specific rules for different modes (e.g., `hardware`, `simulink`, `python_sim`).
4. Modify these string contents according to your needs.

---

## MATLAB/Simulink simulation mode

If you already have a MATLAB/Simulink model, you can tune its PID parameters directly with LLM assistance — no real hardware needed.

Set these fields in `config.json`, then run `python simulator.py` or choose the Simulink mode from the packaged launcher:

- `MATLAB_MODEL_PATH`: path to the Simulink `.slx` file
- `MATLAB_PID_BLOCK_PATH`: full path to the PID block inside the model
- `MATLAB_OUTPUT_SIGNAL`: To Workspace variable name
- `MATLAB_ROOT`: MATLAB install root; recommended for the packaged app, optional for source runs when `matlab.engine` already imports in your Python environment

For full setup instructions, model requirements, and troubleshooting, see the [MATLAB/Simulink Tuning Guide](docs/en-US/MATLAB_GUIDE.md).

---

## No hardware yet? Run the simulator first

```bash
pip install -r requirements.txt
python simulator.py
```

`simulator.py` models a simple local heating system and opens a lightweight Textual terminal dashboard by default when run in an interactive terminal.

Before the tuning loop starts, it now does three beginner-friendly things automatically:

- runs a quick doctor check for config, API reachability, serial ports, expected protocol fields, and proxy settings
- runs a short system-identification warm start so the initial PID is better than the fixed default values
- supports a **Pre-Tuning Conversation** (Interactive mode only), where you can describe tuning preferences and hard constraints in natural language (e.g., "overshoot must be less than 5%"), which the LLM will automatically enforce.

- Press `q` to quit the dashboard
- Press `p` to pause or resume the simulation loop
- Press `l` to toggle concise vs detailed event logs
- Press `r` to clear the event log and temporary summary

If you prefer the old plain log output, or want to explicitly set the language:

```bash
python simulator.py --plain
python simulator.py --lang zh  # Override language to Chinese. The system auto-detects English/Chinese by default.
```

If the current terminal is non-interactive, or if `textual` is not installed yet, the simulator falls back to plain console logs automatically.

If you want to run the startup checks manually without launching the simulator, use:

```bash
python doctor.py
```

---

## Run from source

If you want the latest behavior from source, prefer `dev` over `main`. New fixes, TUI changes, and pre-release validation land on `dev` first, while `main` is the slower-moving stable branch.

### Fresh clone: use `dev`

```bash
git clone -b dev https://github.com/KINGSTON-115/llm-pid-tuner.git
cd llm-pid-tuner
```

### Existing clone: switch to `dev` and update

```bash
git fetch origin
git checkout dev
git pull --ff-only origin dev
```

### Install dependencies

```bash
pip install -r requirements.txt
```

If you plan to run Simulink from source, make sure this same Python environment can import `matlab.engine`. The [MATLAB/Simulink Tuning Guide](docs/en-US/MATLAB_GUIDE.md) covers that setup.

### Before you run

- `python tuner.py`: fill LLM settings and serial settings
- `python simulator.py`: fill LLM settings
- Simulink mode: also fill the `MATLAB_*` fields

If `config.json` does not exist yet, the program will create a default one on first run. You can also start from `config.example.json`.

### Common commands

- `python tuner.py`

- `python simulator.py`
- `python simulator.py --plain`
- `python doctor.py`
- `python system_id.py --file sample_step.csv`
- `python benchmark.py --cases baseline fallback llm --rounds 8`

---

## Main files

| File | Purpose |
| :--- | :--- |
| `launcher.py` | Packaged exe entry that routes to hardware or simulation |
| `tuner.py` | Main hardware tuning runtime |
| `simulator.py` | Local thermal simulation |
| `pid_safety.py` | Guardrails, fallback logic, best-result tracking, rollback |
| `firmware.cpp` | Example MCU firmware |
| `system_id.py` | Step-response based system identification |
| `doctor.py` | Environment check utility to debug config/API issues |
| `benchmark.py` | Fixed-seed comparison utility |
| `docs/en-US/PROJECT_DOC.md` | Developer-oriented project notes |

---

## FAQ

### The exe closes immediately

Common reasons:

- `config.json` is incomplete
- invalid API key
- serial port cannot be opened
- current directory is not writable

Run it from PowerShell to keep the error message visible:

```powershell
.\llm-pid-tuner.exe
```

### The app cannot find my serial port

Check:

- cable / driver
- whether another tool already opened the port
- whether your baud rate matches the firmware

### I get a connection but no useful data

Usually the board is not sending the expected CSV protocol. Start from `firmware.cpp` if possible.

### Can I use it fully offline?

Yes, if you run a local model server such as Ollama or LM Studio and expose an OpenAI-compatible endpoint.

---

## Safety

**Always supervise real hardware during tuning.**

Especially for heating systems, you still need hardware-level protection such as:

- over-temperature cutoff
- sensor failure handling
- power-stage fault protection
- physical power disconnect if necessary

This tool reduces tuning pain. It does not replace hardware safety design.

## License

`CC BY-NC-SA 4.0`

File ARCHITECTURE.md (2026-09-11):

# ARCHITECTURE.md

STM32F407 AGV firmware — 完整架构参考文档。按需查阅，不随每次会话自动加载。

> **提示**：在日常编码中不需要逐页阅读本文。遇到以下情况时查阅对应章节：
> -   修改 GPIO / 外设 / 中断 → §1 Hardware Pins → §2 ISR
> -   修改循迹控制 → §3 Line-Follow
> -   修改视觉/OpenMV → §4 OpenMV → §5 Visual Servo → §6 Vision → §7 AI Pipeline
> -   修改机械臂动作 → §11.3 Servo Power → §11.4 ArmSM
> -   修改串口/CSV → §9 CSV Protocol
> -   调试启动 → §12 Startup → §13 Main Loop
> -   定位 Bug → §15 Bug Tracking

---

## 1. Hardware Pin Mapping (Full)

### DC Motors (4 differential-drive wheels, left/right pairs)

| ID | Name | PWM (Timer) | IN1 | IN2 |
|----|---|---|-----|-----|
| 0 | 左前 | PA7 (TIM3_CH2) | PE3 | PE4 |
| 1 | 右前 | PA6 (TIM3_CH1) | PE5 | PE6 |
| 2 | 左后 | PB1 (TIM3_CH4) | PC8 | PC4 |
| 3 | 右后 | PB15 (TIM12_CH2) | PD3 | PD4 |

Motor PWM: **1kHz** (ARR=999, PSC=83, 84MHz base), duty 0–999.
Speed range: ±1000 (mapped to duty via `speed * 999 / 1000`).

### Servos (4-DOF arm)

| User ID | Joint | PWM (Timer) | Angle range |
|---|---|---|---|
| 0 | 腰座 (waist) | PA8 (TIM1_CH1) | 0–180° |
| 1 | 大臂 (shoulder) | PA9 (TIM1_CH2) | 0–180° |
| 2 | 小臂 (elbow) | PA2 (TIM9_CH1) | 0–180° |
| 3 | 夹爪 (gripper) | PA11 (TIM1_CH4) | 0–180° |

Servo PWM: 50Hz (ARR=19999, PSC=167, 168MHz base), pulse 500–2500.
Note: `pwm.h` defines both `SERVO_ELBOW` (TIM1_CH3/PA10, unused zombie channel) and `SERVO_ELBOW_PA2` (TIM9_CH1/PA2, active). The elbow was remapped from PA10 to PA2 but the old define remains.

### Quadrature Encoders

| ID | Timer | CH1 | CH2 |
|----|---|-----|-----|
| 0 (左前) | TIM5 | PA0 | PA1 |
| 1 (右前) | TIM2 | PA15 | PB3 |
| 2 (左后) | TIM4 | PB6 | PB7 |
| 3 (右后) | TIM8 | PC6 | PC7 |

### Communication & Sensors

| Interface | Peripheral | Pins | Notes |
|---|---|---|---|
| Debug UART | UART5 (115200) | PC12(TX), PD2(RX) | Primary command + CSV telemetry |
| Bluetooth | USART2 (9600) | PD5(TX), PD6(RX) | **Currently disabled** — implemented in `hc_sr40.c/h` (misnamed, NOT ultrasonic). `BT_Init()` commented out, ISR `#if 0`'d. USART2 cannot coexist with UART5 at current NVIC priorities (both would need prio 0,0 to beat TIM6) |
| Line sensor ×5 | GPIO input | PC0, PC1, PC2, PC3, PA4 | Active-low, pull-up, weighted error |
| OLED | I2C | (see `OLEDIIC.c`) | Currently disconnected |
| OpenMV | USART3 (115200) | PC10(TX), PC11(RX) | Camera vision data (`$TAG` packets) |
| CountSensor | EXTI1 on PB1 | PB1 | External interrupt counter; ISR exists but body is empty — hardware is wired but unused |

---

## 2. ISR Priority Layout (Full)

NVIC priorities (lower number = higher priority; preemption priority, subpriority format):

| ISR | Peripheral | File | Priority (pre,sub) | Role |
|-----|---|---|---|---|
| `PVD_IRQHandler` | PVD | `Timer.c` | 0,0 | Brownout: immediate motor brake |
| `UART5_IRQHandler` | UART5 | `uart.c` | 0,0 | Debug UART RX ring buffer (tied with PVD as highest) |
| `TIM6_DAC_IRQHandler` | TIM6 | `Timer.c` | 1,0 | 100Hz control heartbeat |
| `USART2_IRQHandler` | USART2 | `hc_sr40.c` | 2,0 | Bluetooth RX **(disabled via `#if 0`)** |
| `USART3_IRQHandler` | USART3 | `commend_openmv.c` | 2,0 | OpenMV camera RX ring buffer |
| `EXTI1_IRQHandler` | EXTI1 | `CountSensor.c` | 3,3 | Counter input **(empty handler)** |

**Key implication**: UART5 at prio 0,0 can preempt TIM6 (prio 1,0). During heavy CSV telemetry, UART5 ISR steals cycles from the 100Hz control loop. USART2 (BT) is disabled because it would need prio 0,0 to not lose data at 9600 baud, but that conflicts with UART5. If BT is re-enabled, the NVIC priorities must be rebalanced.

---

## 3. Control System Design (Detailed)

**Timer interrupt**: TIM6 fires at **100Hz (10ms)** — the central control heartbeat (`User/Timer.c:TIM6_DAC_IRQHandler`).

**Four operating modes** (`work_mode`):
- `MODE_MANUAL (0)` — Serial commands directly set `target_speed[]`
- `MODE_LINE_FOLLOW (1)` — Line sensor PID → `target_speed[]` per 10ms. Supports timed stop via `line_time_ticks`: when `line_time_ticks > 0 && g_sys_tick >= line_time_ticks`, motors are stopped and mode switches to MANUAL. The `line_time <sec>` serial command sets this (argument in seconds, internally converted to absolute tick).
- `MODE_POSITION (2)` — Position PID outer loop → `target_speed[]` per 20ms
- `MODE_VISUAL_SERVO (3)` — OpenMV vision-guided approach (`#define MODE_VISUAL_SERVO 3` at `visual_servo.h:7`; fully wired into the TIM6 ISR dispatch at `Timer.c:95`)

**Nested PID loops**:
1. **Position loop** (20ms, positional PID `pid_positon[]`): Target position → speed command (±600)
2. **Speed loop** (10ms, incremental PID `pid_motor[]`): Speed command → motor PWM output (±1000)
3. **Line-follow loop** (10ms, positional PID in `line_follow`): Sensor error → turn correction → modifies `target_speed[]`

### 3.1 Line-Follow PID

**Line sensor array** (`User/line_sensor.h`): 5-channel IR on PC0–PC3 + PA4. GPIO reads compared `!= 0` so `states[i]==1` means line detected (header says active-low). Weighted error `{-2,-1,0,1,2}` normalized by detection count → error ±2.

**Line-follow PID** (`User/line_follow.c`): Features sensor debounce (3-sample majority vote in `LineSensor_Read`), deadband on error (±0.1 → zeroed), EMA on derivative (70% old + 30% new), integral separation at ±1.5 error threshold, trapezoidal integration, and turn output clamping at ±600. Output speeds clamped to [0, 1000] (forward-only; inner wheel stops but doesn't reverse on sharp turns). Turn is added to left wheels and subtracted from right wheels (differential steering).

**Line-loss behavior**: When no sensor detects the line, motors coast at 60% of last known speed (±30 min) for 50 ticks (500ms), then integrals zeroed and motors stop. Prevents nuisance stops from brief dropouts.

**Curve detection**: Built-in curve counter (`curve_count`, `curve_target`, `curve_ready` fields in `Line_follow_Handle`). A "curve" is detected when ≤4 of 5 sensors see the line for 3 consecutive frames. After `curve_target` curves + `curve_delay_ms` delay, `curve_ready` is set to 1. This can be used to trigger actions after passing a known number of curves on the track.

**Motor 3 right-rear compensation**: Motor 3 encoder is broken → open-loop control. In line-follow, `right - 20` is applied to motor 3 speed to compensate for its tendency to run faster without encoder feedback. This hardware-specific hack is only in the line-follow path; other modes use `encoder_max[3] = 0` open-loop fallback in the TIM6 ISR.

**Motor direction polarity**: `motor_dir[] = {1, -1, 1, -1}` corrects for motor mounting orientation so positive `target_speed` always means forward.

---

## 4. OpenMV Vision Subsystem

**OpenMV Vision Communication** (`User/commend_openmv.c/h`): USART3 (PC10=TX, PC11=RX, 115200 baud) dedicated to the OpenMV camera. Uses the same ring-buffer ISR + polling pattern as the debug UART. Parses data packets at ~10–50Hz. Three data structures are maintained:

- **`OpenMV_Data`** — AprilTag/color blob tracking: `tag_id`, `cx`, `cy`, `distance_cm`, `angle_deg`, `pixel_width`. Used by visual servo and vision_task.
- **`OpenMV_QRData`** — QR code decoded text (up to 64 chars). Used by the AI auto-scan main-loop pipeline.
- **`OpenMV_CLSData`** — AI classification result: `class_id` (-1=uncertain) and `confidence` (0–100%). Used by the AI auto-scan main-loop pipeline.

All three use a `fresh` flag pattern for ISR-to-main-loop producer-consumer sync. ISR-safe `OpenMV_TagSeenRecently()` queries tag presence by timestamp without consuming data. `OpenMV_PollLine()` drains the ring buffer in the main loop. OpenMV mode is set via `OpenMV_SendCmd("MODE,<mode>")` where mode is `APRILTAG`, `COLOR`, `QRCODE`, or `AI`.

**Serial packet formats** (USART3, 115200 baud):
- `$TAG,<id>,<cx>,<cy>,<dist_cm>,<angle_deg>,<width>` — AprilTag/color blob detection
- `$QR,<payload>` — QR code decoded text
- `$CLS,<class_id>,<confidence>` — AI classification result (class_id=-1 means uncertain)
- `$HB` — Heartbeat (aliveness check via `OpenMV_IsAlive()`)

Commands are sent as `$CMD,<command>\r\n` (e.g. `$CMD,MODE,AI\r\n`).

**OpenMV firmware**: `OpenMV_scripts/main.py` (source backup). The active firmware is on the H7 Plus internal flash (H: drive when USB-connected). Utilities: `train.py`, `capture.py`, `test_*.py`. Models: `model_mid.tflite` (active), `model.tflite`, `model_small.tflite`. Legacy: `vision_main.py` (5-state-machine, not active).

**Model loading**: H7 Plus has 32MB internal flash — no SD card needed. The active model `model_mid.tflite` (~630KB, MobileNetV2 α=0.35 INT8) is loaded via `ml.Model(load_to_fb=True)` from `/flash/`. The model is lazy-loaded on first `MODE,AI` command to avoid blocking startup.

**QR debounce**: QR codes require 3 consecutive frame confirmations; on loss, output is held for 5 frames before clearing. This adds ~150–250ms latency to QR detection/loss transitions.

---

## 5. Visual Servo

**Visual Servo** (`User/visual_servo.c/h`): Implements `MODE_VISUAL_SERVO (3)` — dual PID for autonomous AprilTag docking:
- **Lateral PID**: Steers to center the tag horizontally (target `cx=160`, 320×240 image). Output clamped to ±turn_limit (default 400).
- **Longitudinal PID**: Controls forward/backward speed to reach the target distance. Output clamped to ±base_speed_max (default 150).
- Outputs combined via differential steering: `left = forward + turn`, `right = forward - turn`.
- Features integral separation on both axes, IIR low-pass filter on derivatives (70% new + 30% old), trapezoidal integration, loss-of-tag handling (stops motors after configurable timeout, default 200ms), and hysteresis-based alignment detection (N consecutive frames within tolerances, default 5 frames).
- Follows the same handle-pattern convention as `Line_follow_Handle` — `VisualServo_Task()` is called at 100Hz from the TIM6 ISR.

---

## 6. Vision Task Mission Orchestrator

**Vision Task** (`User/vision_task.c/h`): A high-level, non-blocking state machine that coordinates OpenMV vision data with line-following and arm actions. Three mission types:
- **Color search** (`VIS_COLOR_SEARCH → VIS_COLOR_APPROACH → VIS_COLOR_GRASP → VIS_DONE`): Line-follow until target color blob detected → approach using centroid-based steering → grasp at close range.
- **QR code search** (`VIS_QR_SEARCH → VIS_QR_APPROACH → VIS_QR_EXECUTE → VIS_DONE`): Line-follow until QR code detected → approach → execute decoded command (supports `GRASP` and `PLACE` keywords; defaults to grasp if no command).
- **AI classification scan** (`VIS_AI_SCAN → VIS_AI_APPROACH → VIS_AI_EXECUTE → VIS_DONE`): Stop and classify objects via OpenMV's onboard model → approach detected target → execute action based on class ID.

Each mission type sets the OpenMV mode (`OMV_MODE_COLOR`, `OMV_MODE_QRCODE`, `OMV_MODE_AI`) and switches to line-follow or manual mode as needed. Missions have configurable approach/grasp distance thresholds and 1s target-loss timeout (100 ticks). `VisionTask_Process()` is called from `main()` and throttles to 50ms intervals. State queries via `VisionTask_IsBusy()` / `VisionTask_GetState()`.

---

## 7. Main-Loop AI Pipeline (Primary Autonomous Mission, QR-triggered)

Located inline in `main.c` (`qr_phase` 0–11 state machine, main loop). This is the **active** autonomous mission orchestrator — it replaced the older `#if 0`'d timed auto-mission. **QR 触发**: the pipeline starts by scanning a QR code, approaches to 15cm, then runs AI classification / color alignment / grasp / place. It only activates after docking completes (`dock_state == 5`, `main.c:615`), so it never races the dock state machine. Two stations:

```
Station 0 (抓取放从车): QR 触发 → approach 15cm → 识别(AI 分类, 腰座±20° 扫描) → QuickAlign 色块对准 → 抓取 → 放置到从车(180°) → 下一件
Station 1 (从车取件交付): QR→AI→COLOR 识别从车上物件 → 取件 → 交付
任务序列: mission_idx 0→2, mission_class[] = {0,2,1} (红→黄→绿); 两站跑完 mission_done
关键 phase: 0=QR触发+approach, 1=识别(腰座±20°扫描), 10=QuickAlign 色块对准, 3=抓取,
           11=放置(180°), 7=AprilTag 定位, 9=AI(skip_pick), 8=Station0 下一件, 4/5/6=Station1 取件交付
每阶段独立超时兜底 + `restart`/`run` 一键恢复
```

The pipeline coexists with `VisionTask_Process()` but operates independently. `mission_idx`/`station_idx` are globals (`main.c:94-95`, both start at 0). Lateral alignment uses waist servo rotation + body forward/back; AI classification filters by `mission_class[mission_idx]`.

**class_id → color mapping** (OpenMV model labels → vision_task color IDs):

| class_id | Label | Color ID | OpenMV Mode |
|:--:|---|:--:|---|
| 0 | red_hexagon | 1 (Red) | COLOR |
| 1 | green_circle | 2 (Green) | COLOR |
| 2 | yellow_rect | 3 (Yellow) | COLOR |

---

## 8. TaskQueue System (Mission Sequencer)

`User/state_machine.c/h` defines a **TaskQueue** — a scriptable multi-step mission sequencer (separate from the legacy `TaskNav` and the AI auto-scan pipeline). Up to 16 steps (`TASK_QUEUE_MAX`), each step is a `TaskStep`:

```c
typedef struct {
    uint8_t  travel_mode;    // 0=encoder mileage, 1=line-follow
    int32_t  encoder_dist;   // target encoder counts for this leg
    int16_t  tag_id;         // AprilTag ID for docking (-1 = skip docking)
    int16_t  dock_distance;  // visual servo stop distance (cm)
    uint8_t  action;         // ACTION_GRASP / ACTION_PLACE / ACTION_HOOK / ACTION_UNHOOK / ACTION_NONE
    int16_t  action_param;   // e.g. place waist angle
} TaskStep;
```

TaskQueue state machine: `TQ_TRAVEL → TQ_DOCK → TQ_ACTION → (next step) → TQ_DONE`. During TRAVEL, two triggers can advance to DOCK: (1) encoder mileage reached, or (2) target AprilTag spotted within 100ms (auto-transition to visual servo docking). Per-step timeouts: TRAVEL=30s (3000 ticks), DOCK=10s (1000 ticks), ACTION=8s (800 ticks). Hook/unhook actions (`ACTION_HOOK`/`ACTION_UNHOOK`) call `Action_HookTrailer()`/`Action_UnhookTrailer()` — placeholders for trailer coupling control.

`TaskQueue_Process()` is called from `main()` in the main loop. It is NOT ISR-safe (blocking arm actions use `Delay_ms`).

---

## 9. Debug Interface

Serial commands via **UART5** (wired USB-UART, PC12/PD2) and **Bluetooth USART2** (PD5/PD6, 9600 baud). Both feed into `Commend_Parse()`. `fputc` redirects `printf` to either UART5 or BT based on `uart_set_bt_output()`. Format: `<command> <args>`. Full list via `help` command. Key categories:

- **Motion**: `spd`, `m f|b|l|r|s`, `mode <0-3>`, `stop`, `reset`, `enable <0|1>`, `line_time <sec>`
- **PID tuning**: `kp/ki/kd`, `pos_kp/pos_ki/pos_kd`, `lkp/lki/lkd`, `base_speed`, `PID`, `SET KP:...`, `SETPOINT:`
- **Encoder**: `enc_pos`, `enc_speed`, `enc_max`, `enc_dir`, `enc_clear`, `enc_raw`, `enc_speed_all`, `pid_dbg`
- **Servo**: `servo`, `s_smooth`, `servo_on/off`, `a_set`, `t_set`, `show_act`
- **Arm**: `grasp`, `place <waist>`, `reset_arm`, `show`
- **OpenMV**: `vmode`, `vcolor`, `vtag`, `vqr`, `vfind`, `vqrgo`, `vfind_ai`, `vstop`, `vdata`, `vqrtext`, `vcls`, `vstat`
- **Task**: `task_start`, `task_stop`, `task_status`
- **System**: `save/load` (placeholder), `BT`

---

## 10. CSV Data Protocol & LLM PID Tuner

The main loop sends PID telemetry over UART5 every 50ms (5 `g_sys_tick` units) via `sendPIDDataToUART()` in `User/command.c`. **Currently `sendPIDDataToUART()` is commented out at `main.c:1125` — uncomment it to enable the CSV stream for the LLM PID Tuner.** Each print produces 4 lines (one per motor):

```
<motor_id>,<tick>,<setpoint>,<speed>,<output>,<error>,<Kp>,<Ki>,<Kd>\r\n
```

Note the order: `motor_id` (int) comes first, then `tick` (uint32_t, formatted as `%lu`).

**`llm-pid-tuner-dev/`** is a companion Python project that reads this CSV stream over serial and uses an LLM (OpenAI/Claude/Ollama/etc.) to auto-tune motor PID gains. See its `README.md` for setup. Key files:
- `tuner.py` — real-hardware tuning entry point
- `simulator.py` — local thermal system simulation (no hardware needed)
- `pid_safety.py` — parameter guardrails, rollback to best-known-stable params
- `doctor.py` — environment diagnostics (API connectivity, serial port check)
- `firmware.cpp` — reference Arduino/ESP32 firmware implementing the same CSV protocol

The tuner sends PID updates as serial text commands the existing command parser already handles: `kp/ki/kd <id> <val>` and bulk `SET KP:<p> KI:<i> KD:<d> [M:<id>]`.

---

## 11. Key Architecture Details

### 11.1 Global Tick
`volatile uint32_t g_sys_tick` increments at 100Hz in the TIM6 ISR (`User/Timer.c`). Used by `main()` for periodic tasks (LED heartbeat every ~500k loop iterations, CSV reporting every 5 ticks).

### 11.2 Volatile Shared Variables (ISR ↔ main loop)

These are read/written by both ISR and main-loop code — never assume they stay constant across multiple main-loop statements.

| Variable | Location | Writer | Readers |
|---|---|---|---|
| `g_sys_tick` | `Timer.c` | TIM6 ISR | main loop, line_follow, vision_task |
| `target_speed[4]` | `main.c` | TIM6 ISR (speed PID output), main loop (manual/vision) | TIM6 ISR (PWM output) |
| `work_mode` | `main.c` | main loop (serial cmd) | TIM6 ISR (dispatch) |
| `motor_enable` | `main.c` | main loop, PVD ISR | TIM6 ISR (gates PWM output) |
| `line_time_ticks` | `Timer.c` | main loop (`line_time` cmd) | TIM6 ISR (line-follow stop check) |
| `g_sys_ms` | `DELAY.c` | SysTick ISR (1ms) | `Delay_ms()`, `Delay_Start()` |
| `rx_buf[]/rx_head/rx_tail` | `uart.c` | UART5 ISR (write head) | main loop (read tail) |
| `omv_rx_buf[]/head/tail` | `commend_openmv.c` | USART3 ISR (write head) | main loop (`OpenMV_PollLine()`) |
| `omv_qr_fresh/buf` | `commend_openmv.c` | USART3 ISR | main loop (AI pipeline) |
| `omv_cls_fresh/data` | `commend_openmv.c` | USART3 ISR | main loop (AI pipeline) |
| `omv_ai_ready` | `commend_openmv.c` | USART3 ISR (`$OK,BOOT`) | main loop (AI init wait) |
| `omv_model_error` | `commend_openmv.c` | USART3 ISR (`$ERR`) | main loop (AI error check) |
| `omv_last_hb_tick` | `commend_openmv.c` | USART3 ISR (`$HB`) | main loop (`OpenMV_IsAlive()`) |

**Rule**: In main-loop code, take a local snapshot of any ISR-shared variable you check more than once (e.g. `uint32_t tick = g_sys_tick;` then use `tick`). The compiler may re-read the `volatile` from memory each time, giving inconsistent values.

### 11.3 PID Features
Both position and incremental PID include integral separation (integral zeroed when |error| > threshold), back-calculation anti-windup (stop integrating when output saturated in same direction as error), trapezoidal integration, and a first-order IIR low-pass filter on the derivative term. Default speed PID gains (incremental): motors 0,1 → Kp=5.5 Ki=0.16 Kd=0; motors 2,3 → Kp=5.0 Ki=0.14 Kd=0. Default position PID: Kp=0.5 Ki=0.001 Kd=0. Default line-follow: base_speed=180, Kp=180.0 Ki=2.0 Kd=2.0.

### 11.4 Motor & Encoder Polarity
`motor_dir[] = {1, -1, 1, -1}` and `encoder_dir[] = {-1, -1, -1, -1}` (all-negative default) correct for physical mounting orientation. Sensor data is multiplied by `encoder_dir[i]` before speed PID; speed commands are multiplied by `motor_dir[i]` before PWM output. A positive `target_speed` always means "forward" at the application level.

### 11.5 Hardware Limitations
Motor 3 (右后) encoder is physically broken — `encoder_max[3] = 0` in main.c, which triggers open-loop fallback in the TIM6 ISR (speed command mapped directly to PWM without PID feedback). The OLED display is physically disconnected — `OLED_Init()` is commented out to avoid I2C timeout stalling startup. Navigation encoder averaging in `TaskNav_Process()` and `TaskQueue_Process()` uses only motors 0–2, excluding motor 3.

### 11.6 Smooth Servo
(`User/smooth_servo.c`): Uses quintic (5th-order) polynomial smoothstep interpolation for jerk-limited servo motion. Called from TIM6 ISR at 100Hz. Includes automatic speed limiting — if the requested motion exceeds `MAX_ANGULAR_VEL` (180°/s peak), the duration is automatically extended.

### 11.7 Servo Power Management
(`smooth_servo.c:168-177`): After reaching target position, each servo has custom power-off behavior (reduces heat and power draw): (1) **Shoulder (ID 1) + Elbow (ID 2)** — always stays powered on (holds against gravity); (2) **Waist (ID 0)** — powered off permanently after reaching position; (3) **Gripper (ID 3)** — cycle mode (hold 500ms → off 5s → re-power 500ms → repeat). If modifying servo behavior, check the `HOLD_TICKS`/`OFF_TICKS`/`ON_TICKS` timing constants.

### 11.8 Arm State Machine
(`User/state_machine.h`): Tracks `ArmState` enum (IDLE/GRASPING/PLACING/RESETTING/ESTOP). Action sequences in `action_group.c` check state before executing and reject overlapping commands with "Arm busy". Features 50ms debounce on state transitions (DEBOUNCE_TICKS=5, checked at 100Hz in `ArmSM_Tick10ms()`) and per-operation timeouts via `ArmSM_Tick10ms()` (30s grasp, 30s place, 30s reset → auto-ESTOP). Overlapping requests return 0 (rejected); callers should check `ArmSM_IsBusy()` before requesting.

### 11.9 Legacy AGV Task Navigation
(`User/state_machine.c`): The `TaskNav` state machine executes full autonomous missions: `TASK_IDLE → TASK_GO_TO_A (line-follow to pickup) → TASK_GRASP (arm grasp) → TASK_GO_TO_B (line-follow to delivery) → TASK_PLACE (arm place) → TASK_DONE`. Progress is measured via encoder averaging (motors 0–2 only; motor 3 encoder is broken). `TaskNav_Process()` is called from main loop at ~100Hz but throttles distance checks to 50ms intervals. Arm actions within it are blocking (use `Delay_ms`), which is safe in the main loop but NOT in ISR context. Each travel leg has a 30s timeout.

### 11.10 PVD Brownout Protection
(`User/Timer.c:PVD_Init`): Configures PVD interrupt at 2.9V threshold (PWR_PVDLevel_7). When VDD drops below 2.9V, `PVD_IRQHandler` immediately brakes all motors and sets `motor_enable = 0`. Priority is NVIC priority 0,0 — the highest in the system.

### 11.11 Encoder Safety
(`User/enconder.c`): IIR low-pass filter (70% prev + 30% new) on speed. Fault detection: delta >10× max → 10 consecutive = force-resync. 16-bit counter wraparound handled.

### 11.12 JTAG Release
`Encoder_Init()` remaps PA15/PB3 from JTAG to GPIO_AF_TIM2, keeping only SWD (PA13/PA14). `DBGMCU->CR` trace pins (PE2–PE6) disabled in `main()`.

### 11.13 Stack/Heap Constraints
(from `startup_stm32f40xx.s`): Stack size = **1024 bytes** (`0x400`), Heap size = **512 bytes** (`0x200`). These are very small — avoid deep call stacks, large local arrays, and dynamic allocation (`malloc`/`new`). A stack overflow will silently corrupt `.data` or heap. No MPU is configured to catch overflows. If adding recursive functions, deeply nested calls, or large local buffers (>256 bytes), increase the stack size in the startup file.

### 11.14 Ring Buffer Pattern
Both UART5 (debug) and USART3 (OpenMV) use the same ring-buffer ISR + main-loop polling pattern. ISR pushes bytes into a circular buffer; the main loop drains them with `uart_rb_getchar()` (UART5) or `OpenMV_PollLine()` (OpenMV). During `printf()` bursts, ISR silently captures bytes to prevent data loss. Never poll RXNE directly from the main loop — it races with the ISR.

### 11.15 `__weak` Parameter Hooks
`Save_parameters()` and `Load_parameters()` are declared `__weak` in `command.c`. They're currently empty placeholders but can be overridden in another translation unit to implement persistent PID parameter storage (e.g., in Flash or EEPROM). The `save`/`load` serial commands call these.

### 11.16 Mode Define Duplication
`MODE_MANUAL`/`MODE_LINE_FOLLOW`/`MODE_POSITION` are in both `line_follow.h` and `main.c`; `MODE_VISUAL_SERVO` only in `visual_servo.h`. Check both locations when modifying mode constants.

---

## 12. Startup Sequence

(`User/main.c`):
1. `Motor_EmergencyBrake()` — immediately grounds all motor IN pins before any slow peripheral init (prevents floating-IN startup runaway)
2. SystemInit → SysTick (1ms) → NVIC config → disable DBGMCU trace pins (PE2–PE6)
3. LED_Init → UART5 init → print "a\r\n" (power-on alive signal) → OpenMV USART3 init (Bluetooth `BT_Init()` is commented out — USART2 is currently unused)
4. Motor + PWM init → Delay_ms(200) → Servo + SmoothServo + Arm state machine + Action param init + VisionTask init
5. VisualServo init (any tag, 15cm stop distance, default PID) + TaskQueue init
6. Encoder + line sensor init
7. PID + line-follow init with default gains
8. TIM6 100Hz ISR start + PVD enable
9. All PID states zeroed, `motor_enable = 0`, target_speed[] cleared, motors stopped
10. `motor_enable = 1; work_mode = MODE_LINE_FOLLOW` — auto-enter line-following (上电直接进循迹)
11. `Action_Reset()` → wait for idle → LED blinks 3 times (MCU-alive heartbeat)
12. Enter `while(1)` — serial command processing + AI auto-scan pipeline + periodic tasks

Note: The **timed auto-mission** (grasp at 5s, place at ~22s) is **disabled** via `#if 0` at `main.c:228`. It has been replaced by the AI auto-scan pipeline and the TaskQueue system.

Note: **开跑整流程 (auto-start run flow)** — boot sets `cross_dock_enable=1` (crossroad auto-dock ON) and prints the `AGV RUN FLOW READY` banner; the robot then runs: line-follow → 十字路口(5路全踩) → 右拐脱线对准 → AprilTag 倒车对接挂钩 → Station0(抓3件放从车) → Station1(从车取件交付) → LED 三闪完成. Serial `run`/`restart` performs a full-flow reset (AI pipeline `qr_phase`/mission/station counters + dock state machine + `dock_done_once`), returning to line-following.

Note: `MotorSelfTest()` (sequential ±400 pulse per motor) is defined as a static function in `main.c` but is **not called** in the current startup sequence — it exists for manual debugging if needed.

---

## 13. Main Loop Detail

(`User/main.c`): After init, the robot is already in `MODE_LINE_FOLLOW` — line-following runs autonomously in the TIM6 ISR. The `while(1)` loop handles:
1. UART5 serial command input (ring-buffer drain only — **no direct RXNE polling**; ISR handles all RX to avoid hardware register races)
   - **Startup silent period**: For the first 300 ticks (3s) after entering the main loop, incoming UART chars are parsed silently — no echo, but commands still execute. After 3s, printable ASCII chars are echoed back. This suppresses USB-TTL noise during power-up.
   - **Error filtering**: UART bytes with Frame Error (FE) or Noise Error (NE) flags are silently discarded (by ISR) — prevents garbage from polluting the command buffer during power transients.
   - Ring buffer ISR captures all bytes; main loop drains them via `uart_rb_getchar()`. Direct RXNE polling from main loop would race with the ISR and is explicitly avoided (see `main.c:222-223`).
2. AI pipeline (`qr_phase` 0–11, QR-triggered; gated on `dock_state==5`) + dock 状态机 (`dock_state` 0–7, 从车对接)
3. LED heartbeat (~500k loop iterations per toggle)
4. CSV PID telemetry placeholder (currently commented out)
5. `OpenMV_PollLine()` for vision data ring-buffer drain
6. `TaskNav_Process()` (legacy AGV navigation)
7. `VisionTask_Process()` (color/QR/AI mission orchestrator)
8. `TaskQueue_Process()` (scriptable multi-step mission sequencer)
9. Bluetooth command input via `BT_GetLine()`

UART bytes arriving during `printf()` bursts are captured by ISR into a ring buffer and replayed when the main loop drains it — preventing data loss during CSV telemetry output.

---

## 14. 从车拖挂 + 视觉伺服对接

从车是纯机械拖斗（无电无MCU），前面贴 AprilTag 供对接。设计决策：箱子抓取用巡线+腰座比例转向（±5cm）；从车对接用视觉伺服双PID（需±1cm硬连接精度）。`vision_task.c` 管箱子抓取，`visual_servo.c` 管对接 PID，`main.c` 内联 `dock_state` 0–7 状态机编排整条对接链（十字路口→右转→找码→倒车→挂钩→回轨）。对接流程：巡线到十字路口（5路全踩）→原地右转90°脱线→找 AprilTag ID=1→`VisualServo_TaskReverse` 双PID精确倒车（横向差速转向+纵向线性减速，右后/右前开环补偿）→到位停车挂钩→回轨切回 `MODE_LINE_FOLLOW`。丢码 1s（`miss>100`）刹车回找码；找码 30s 总超时放弃对接恢复巡线。调参见 `READY.md`「从车对接实机验证 (2026-08-24)」。

---

## 15. Bug Tracking (Bug#1–#7)

Active design issues/hazards tagged as `Bug#N` in comments throughout the codebase. These are known limitations, not undiscovered bugs:

| Bug | Description | Location |
|:---|:---|:---|
| **Bug#1** | Phase 2 hard timeout uses a separate timer not reset by frame refreshes | `main.c:287,421,584` |
| **Bug#2** | Cross-task scan state (`nodata_start`, `scan_step`, `scan_tick`) must be manually reset when transitioning tasks | `main.c:288,414,597` |
| **Bug#3** | ArmSM return value must be checked before calling `Action_Grasp()`/`Action_Place()` | `main.c:623`, `state_machine.c:271,322` |
| **Bug#4** | Phase 1 waist servo scans ±20° around center after 2s to increase detection range | `main.c:293,373` |
| **Bug#5** | OpenMV `$ERR` packets are parsed but main-loop error handling is not fully wired | `commend_openmv.c:29,264` |
| **Bug#6** | 50ms delay after OpenMV mode switch prevents stale first-frame data | `main.c:408` |
| **Bug#7** | UART ring-buffer peeking for "stop" during blocking arm actions enables software emergency stop | `action_group.c:63,67` |

When editing code near any Bug# tag, read the surrounding comments for context.

---

## 16. State Machines Summary (7 total)

| State Machine | Location | Context | Trigger | Purpose |
|:---|:---|:---|:---|:---|
| `ArmSM` | `state_machine.c` | TIM6 ISR (10ms tick) | Serial cmd / TaskNav / TaskQueue / QR pipeline | Arm busy/lockout + timeout guard |
| `TaskNav` | `state_machine.c` | main loop (50ms throttle) | `task_start` serial cmd | Legacy 2-leg go-grasp-go-place mission |
| `TaskQueue` | `state_machine.c` | main loop | API call (`TaskQueue_AddStep()` + `TaskQueue_Start()`) | Scriptable N-step mission with visual docking |
| `VisionTask` | `vision_task.c` | main loop (50ms throttle) | `vfind`/`vqrgo`/`vfind_ai` cmd | Color/QR/AI search-approach-execute |
| AI pipeline | `main.c` (inline, `qr_phase` 0–11) | main loop | QR 触发 + `dock_state==5` | QR→AI/color align→grasp/place (Station0/1) |
| dock 状态机 | `main.c` (inline, `dock_state` 0–7) | main loop | 十字路口 5路全踩 / `crossdock` 命令 | 从车对接: 停车→原地右转→找 AprilTag→倒车→挂钩 |
| `VisualServo` | `visual_servo.c` | TIM6 ISR (100Hz) | `work_mode == 3` | Low-level dual-PID docking control |

**Rule**: Any code that calls `Action_Grasp()`/`Action_Place()` must first check `ArmSM_IsBusy()` or use `ArmSM_RequestGrasp()`/`ArmSM_RequestPlace()` which return 0 if the arm is busy. Call `ArmSM_NotifyComplete()` after the action finishes.

---

## 17. Key Tunable Constants

| Constant | File | Default | Purpose |
|---|---|---|---|
| `MAX_ANGULAR_VEL` | `smooth_servo.c` | 180°/s | Servo speed cap |
| `RX_BUF_SIZE` | `uart.c` | 512 | Debug UART ring buffer |
| `OMV_BUF_SIZE` | `commend_openmv.h` | 256 | OpenMV ring buffer |
| `TASK_QUEUE_MAX` | `state_machine.h` | 16 | Max mission steps |
| `TIMEOUT_GRASP/PLACE/RESET` | `state_machine.c` | 3000 ticks (30s) | Arm action timeout |
| `DEBOUNCE_TICKS` | `state_machine.c` | 5 (50ms) | ArmSM state debounce |
| `DEFAULT_APPROACH_DIST` | `vision_task.c` | 15cm | Vision approach trigger |
| `DEFAULT_GRASP_DIST` | `vision_task.c` | 8cm | Vision grasp trigger |
| `DEFAULT_LOST_TIMEOUT` | `vision_task.c` | 100 ticks (1s) | Target loss timeout |
| `APPROACH_BASE_SPEED` | `vision_task.c` | 100 | Vision approach base speed |
| `WAIST_ADJUST_GAIN` | `vision_task.c` | 0.12°/px | Waist steering gain |
| `APPROACH_SPEED_SLOW` | `vision_task.c` | 60 | AI approach slow speed |
| `PID_DEFAULT_DT` | `pid.c` | 0.01 (10ms) | PID sample time |

---

## 18. Karpathy 编码指南

行为准则：编码前思考（明确假设、呈现权衡）、简洁优先（最少代码、不过度推测）、精准修改（只碰必须碰的、匹配现有风格）、目标驱动执行（定义成功标准、循环验证）。详见用户记忆。

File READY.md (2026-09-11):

# AGV 智能搬运机器人 — 开发记录

## 当前状态 (2026-06-23)

### 硬件
- STM32F407 + 4 轮差速驱动 + 4-DOF 机械臂
- OpenMV 摄像头 (USART3, 115200)
- 5 路巡线传感器
- SD 卡 ✅ (已购买, AI 模型已训练部署)

### 已完成
- [x] AI 模型训练 + 部署 (MobileNetV2 α=0.35, int8量化, 三分类)
- [x] QR + AI + 颜色对准 + 抓取 全流程联调
- [x] 三物体依次抓取演示视频录制
- [x] 视觉伺服双 PID 框架 (visual_servo.c, 278行)
- [x] 视觉伺服 PID 串口调参命令 (vkp/vki/vkd/vkp2/vki2/vkd2/vdist/vcx/vpid)
- [x] LLM PID Tuner 框架就绪 (stm32f407_openmv 双控制器 profile)
- [x] 6 状态机全部实现 (ArmSM / TaskNav / TaskQueue / VisionTask / AI pipeline / VisualServo)

### 控制参数
| 参数 | 值 |
|---|-----|
| 巡线 base_speed | 180 |
| 巡线 Kp/Ki/Kd | 180 / 2.0 / 2.0 |
| 转向钳制 | ±600 |
| 右后轮偏置 | -20 (编码器坏, 开环) |
| 视觉伺服默认参数 | lat: Kp=3.0 Ki=0.05 Kd=0.5 / long: Kp=2.0 Ki=0.02 Kd=0.3 |
| 视觉伺服默认目标 | cx=160, dist=15cm |

---

## 开跑整流程 (自动启动, 2026-06-23)

**上电后无需任何串口命令自动开跑**:

```
上电 → LED 三闪 (MCU 就绪)
  → 巡线出发 (OpenMV=QRCODE)
  → 十字路口 (5 路全踩, cross_dock_enable=1 默认开启)
  → 右拐 → 脱线对准 → AprilTag 倒车对接 → 挂钩 (trailer_docked=1)
  → 巡线到 Station 0 → QR → AI/COLOR 识别 → 抓取 3 件 → 放从车
  → 巡线到 Station 1 → 从车取件 → 交付 → 全部完成 LED 三闪
```

- **boot 默认**: `cross_dock_enable=1` (十字路口自动对接开), `crossdock 0/1` 可随时切换。
- **`run`** 一键重置整个流程: AI pipeline + dock 状态机 + 工位计数全部清零 → 回到巡线, 下个十字路口重新对接。
- **`restart`** 与 `run` 等价 (现场备用一键重置)。
- 观察: 串口可看到 `AGV RUN FLOW READY` 开机横幅 + `DOCK: ...` 对接各阶段 + `Station %d: ...` 工位日志; `dockstat` / `trace` 可实时查看对接状态机。

### 调试命令 (2026-06-23 新增一批)

| 命令 | 用途 |
|---|---|
| `flow` | **全流程状态一屏 dump**: 模式/使能/十字开关 + dock_state/turning/lost/tune + qr_phase/工位计数/类别 + 电机速度/腰座角 |
| `ls` | 巡线 5 路传感器: 消抖后状态 `[R1 R2 C L2 L1]` + 原始电平 + `all_on`(十字路口检测) — **现场调右拐必用** |
| `dock_force <0-6>` | 强制跳转 dock 状态机 (1=右拐需自动置 turning) |
| `arm` | ArmSM 状态 + 5 路舵机当前角度/忙闲 (0-4 含挂钩) |
| `pid_all` | 4 路电机速度 PID + 位置 PID + 巡线 PID + 弯道计数 一屏 |
| `enc_all` | 4 路编码器 pos/spd/max/dir |
| `uptime` | 开机时长 (ticks 与秒) |

### ⚠️ 巡线传感器极性: 黑线=GPIO高, 切勿再反转! (2026-06-23 实证)

**结论**: 传感器输出是**高电平有效** — 黑线 → GPIO **高** → `states=1` = 检测到线,
`line_sensor.c` 用 `!= 0` 是对的, **不要再改**。`line_sensor.h` 注释已改为
"active-high: 黑线=GPIO高=1=检测到线"。

**坑**: "检测到黑线灭灯" 是**模块指示灯**灭, 不代表输出电平低 (指示灯驱动与输出反相)。
曾据此把 `!= 0` 误改成 `== 0`, 导致:
- 十字路口 5 路全黑 → GPIO 全高 → `states` 全 0 → `AllOn()` 永不触发 → 不检测不停车;
- 巡线把全黑误判"丢线"滑行 → 轮子/编码器乱动 (用户实测: "五路全灭但没检测到没停, 编码器乱转")。
已改回 `!= 0`, 同步恢复 `ls` 命令原始电平打印。

### 十字路口原地右转90° 方案 (2026-06-23, 最终版, 实车通过)

**检测到十字 → 停车 → 原地差速右转90° → 停 → 转腰座对接 (dock_state 2)**。实车已转起来, 仅剩角度微调。

关键修复链 (按时间):
1. 传感器极性: **黑线=GPIO高** (`!=0`, 勿反转; "灭灯"是模块指示灯与输出反相)。
2. 停车必 `PID_Reset` 4 个电机速度 PID (否则右轮 PID 输出卡前进方向 → 偏右前进)。
3. **右转改开环直驱** (`motor_enable=0` + `Motor_SetSpeed`), 右前轮闭环在负目标下因编码器噪声成"小幅正转"。
4. **`Motor_SetSpeed` 必须乘 `motor_dir`**: 右前/右后(dir=-1)的 IN1 才是倒转方向, 直接传 -200 会变前进(实测直行)。四轮实际 out=+170, 左轮前进右轮倒转 → 原地右转。
5. 90° 判据: "深离开"(在线≤2)后 "≥4路在线"(对齐竖线; 右端 ls[0] 实测不亮, 不能用中心+两端); 最小旋转1.5s; 4s 兜底; 8s 安全超时。
6. 速度 200→170 减小刹车过冲 ("多右一点点"标定)。

标定: 转多了降 `DOCK_PIVOT_SPD`, 转少了升; 若主停因是 4s 兜底则调 `DOCK_PIVOT_CAP` (角度≈时间×速度)。

### 无人值守加固 (2026-06-23, 无串口调试场景)

- **dock_state 2 找码 30s 总超时**: 找不到 AprilTag ID=1 时不再无限扫摆卡死, 自动放弃对接恢复巡线 (对接跳过, 工位流程照常跑, 无拖挂盲放)。
- **LED 阶段指示 (GPIOF Pin9, 无串口可看进度)**: `flow_stage` 1=巡线(慢闪500ms) → 2=对接(快闪100ms) → 3=工位(中闪250ms) → 4=全部完成(常亮)。
- **所有环节均有超时兜底**: 右拐3s、找码30s、识别/定位/对准各15s/15s/5s、机械臂动作30s, 任何一步失败都会降级继续, 不会永久卡死。

### Station 0 识别修复 (2026-06-23, 上电自动跑全流程识别的前提)

原 STATION_MODE 里 **Station 0 发 `MODE,AI` 但 case1 识别/定位阶段只读 `$TAG` 色块数据** (COLOR 模式输出), 而 AI 模式 OpenMV 只发 `$CLS` 分类(无位置) → Station 0 的"识别色卡→定位→对准"会**全部超时, 变成盲抓**。已修复:
- case 0 Station 0 分支 + case 8 Station 0 下一件分支: 统一改为 `MODE,COLOR,x` + 设置 `qr_target_color` + 腰座到识别位 (`identify_waist`), 与 Station 1 完全一致。
- 识别流程: 90°识别色卡(COLOR) → 170°定位色块 → QuickAlign → 抓取 → 放从车。`$CLS` AI 分类目前在 `#if !STATION_MODE` 分支保留 (答辩素材)。

原 `dock_state==1` 右拐判定有两个致命问题, 已修复:
1. **传感器索引错误**: 查 `ls[3]||ls[4]` (line_sensor.c 里是 LEFT2/LEFT1), 注释却写 RIGHT2/RIGHT1。右转弧线中横线从**右臂**扫过传感器, 右侧其实是 `ls[0]`(RIGHT1=PA4)/`ls[1]`(RIGHT2=PC3)。查左传感器 → 永远等不到"进右线" → 3s 超时, 对接卡死。
2. **起步瞬间误触发**: 转弯刚开始 5 路全在十字横线上, 直接判"进右线"立即为真 → 根本没拐, 直行穿十字路口。

修复: 改查 `ls[0]||ls[1]` + 起步保护 `DOCK_TURN_GUARD_TICKS=15` (前 150ms 不判压线, 且要求 `online<5` 已离开十字路口); 超时后复位 `dock_state=0` + `trailer_dock_flag=0`, 下个十字路口自动重试, 不再静默卡死。右拐速度仍为 左+180/右−40 (转弯半径 ≈0.32×轮距, 可画弧拐 90°)。

---

## 从车对接实机验证 (2026-08-24) ✅ 调参通过

**状态**: dock_tune 自动循环连续 3 次 `OK reached` (40cm 到位), 对接闭环稳定。

### 最终生效参数 (已烧录验证)
| 参数 | 值 | 说明 |
|---|-----|---|
| 视觉伺服目标距离 | **40cm** (VisualServo_Init) | 触发到位/挂钩距离 |
| 视觉伺服 base | 160 | 全速倒车 |
| 横向 PID (lat) | **P-only kp=1.0** (I/D=0) | 轮子差速转向 |
| 纵向 PID (long) | **P-only kp=1.5** (I/D=0) | 倒车速度 |
| 目标 cx | 160 | 图像中心 |
| 右后轮补偿 | **DOCK_RR_PCT=7%** | 开环减速补偿 |
| 右前轮补偿 | **DOCK_RF_PCT=15%** | 低速出力不足补偿 (仅倒车) |
| 降速段保底速度 | **-70** | 防止过不了电机死区 |
| 速度曲线 | 线性减速 | dist≥45 全速 / 40-45 线性 / ≤40 停 |
| 丢码策略 | **丢码即刹车** (miss>250) | 不滑行, 回找码 |

### 本轮修掉的坑 (重要经验)
1. **OpenMV 固件禁用 `image.TAG36H11` 显式引用** — 固件未 `import image`, 会抛 "name 'image' isn't defined" → 主循环 catch → mode=IDLE → 只发 $HB 不发 $TAG (vstat 可见 HB=697 TAG=0)。`find_apriltags()` 默认 family 就是 TAG36H11, 不要显式传。
2. **禁用 normalize()/median_filter** — 实测破坏 AprilTag 精确边界导致漏检。
3. **速度曲线断崖** — 原逻辑 dist 38↔39cm 速度 -160→-4.5 断崖, 车"突进→停"; 改线性减速。
4. **倒车安全钳制** — right=forward+turn 在 forward 小时 turn 会把轮子推成正转(前进), 车斜着前拱; 钳制 |turn|≤|forward|, 转向需求大时 forward 归零原地转。
5. **丢码滑行会带偏** — 删掉 coast 滑行, 丢码即停。
6. **降速段保底 -30 太低** — 被 turn 分走后过不了死区, 提到 -70。
7. **st=2 每次扫摆重发 MODE,APRILTAG** — 心跳活着≠模式正确, 只靠掉线检测永远等不到 $TAG。
8. **st=3 腰座等待** — dock_tune/dock_test 直进 st=3 时腰座还在转(5→180°), 等待到位再开始倒车计时。

### ✅ 最终确认形态 (2026-08-24, 以用户参数表为准)

**倒车对接最终调好形态**（`dock_state 3` 与起步首帧一致，差速 + 双轮补偿，勿改回"强制直线"或"开环"）：

```c
motor_enable = 1;                                        // 闭环(用户明确否决开环: "倒车不能开环,我是视觉伺服pid")
work_mode = MODE_MANUAL;
VisualServo_TaskReverse(&visual_servo, &omv_d, target_speed);
target_speed[3] += (int16_t)((-target_speed[3]) * DOCK_RR_PCT / 100);   // 右后轮减速 7% (开环, 偏快)
if (target_speed[1] < 0)
    target_speed[1] += (int16_t)(target_speed[1] * DOCK_RF_PCT / 100);  // 右前轮加力 15% (低速过死区)
```

**参数汇总 (勿再改)**：
- 视觉伺服: 目标 40cm / base 160 / 横向 P=1.0 / 纵向 P=1.5 (均 P-only) / cx=160
- 补偿: `DOCK_RR_PCT=7` (右后减速) + `DOCK_RF_PCT=15` (右前加力)
- 速度曲线: ≥45cm 全速 -160 / 40-45 线性→保底 -70 / ≤40 停
- 倒车安全: forward 单向≤0, |turn|≤|forward| 钳制, 横向死区 ±3px
- 丢码: miss>100 (1s) 刹车回找码; ≤40cm 丢码直接判到位
- 调参循环 (state 6): 前进 120, 右后 112 (=120×93%, 7% 减速)
- 右拐: `DOCK_PIVOT_SPD` 现场按角度微调 (215→200), `DOCK_PIVOT_CAP=330`

**✅ 最终方案 (2026-08-24 实测一次挂钩成功)**：**视觉伺服主回路保留 + 内环开环** — `DOCK_INNER_OPENLOOP=1` (main.c)。即 `VisualServo_TaskReverse` 双 PID 照常算 target_speed，但跳过编码器速度内环，target_speed 直接 `Motor_SetSpeed(motor_dir×target)` 映射 PWM (同右拐 dock_state 1 的直驱方式)。原因: 编码器方向间歇性乱 (接触不良), 速度环正反馈 → 车原地转/不后退; 开环后编码器不再干扰, 视觉伺服靠 RR/RF 补偿保证左右一致性。

**已否决的方向 (实测记录, 勿再试)**：差速被否后曾改"强制直线+腰座对准" (009d4be0 试过)、RR 改 15%/25% 加大 (右后死区不动)、整体开环(不用视觉伺服) (用户否决) — 注意"内环开环"≠"整体开环": 内环开环保留视觉伺服主回路, 是最终方案。

**⚠️ 勿改 encoder_dir 全局方向 (2026-08-24 教训)**：`encoder_dir={-1,-1,-1,-1}` 是**全局**的 (巡线速度环也用), 曾误以为左前/左后倒车 real 为正=方向反, 改成 `{1,-1,1,-1}` → **巡线左轮失控乱跑**。已撤销。倒车 real 时正时负 (motor0 从 -228→+73→+84) 说明是**编码器间歇性接触不良** (方向随机跳), 不是固定反向 → 固定改 encoder_dir 无效且破坏巡线, **只能查硬件接线/供电**。

**⚠️ 逻辑冲突修复 (2026-08-24, "对接时车往前跑")**：
1. **AI 流水线与 dock 状态机无互斥** — 原 `if (!dock_tune_on)` 不检查 dock_state, dock 收尾切 QRCODE 后 AI 立即被 QR 触发 approach 前进, 抢 motor/OpenMV → 车往前跑。已改 `if (!dock_tune_on && dock_state == 5)` (AI 只在 dock 完成后激活)。
2. **丢码刹车阈值** — 原 `miss > 250`(2.5s 滑行) → 先改 `miss > 30`(0.3s) 太紧: OpenMV APRILTAG ~200ms/帧 + 偶发延迟 → 正常帧间隙被误判丢码, 车刚起步就刹 → "不往后走"。**最终 `miss > 100` (1s)**: 覆盖 5 帧+延迟不误判, 真丢码 1s 刹。

**编码器提示 (已绕过)**: 倒车斜/不后退的**根因是编码器读数不可靠** (RDK real 三路时正时负/幅度爆炸, 右拐 enc 有时 0 有时 6 万, 方向随机跳 = 接触不良)。已用"内环开环"绕过, **对接不再依赖编码器**。但巡线 (LINE_FOLLOW) 仍走速度环 — 若日后巡线也打摆/走不直, 才是编码器连前进方向也影响了, 需查那几路接线/供电。

### OpenMV 固件 (H盘 main.py)
- `TAG_W_CM = 10.0` (10cm 码), `FOCAL_TAG = 282` (纯焦距, 与码尺寸无关)
- `run_apriltag()`: `img.find_apriltags()` 无参调用 (默认 TAG36H11)
- 上电默认 QRCODE 模式, 需 `MODE,APRILTAG` 切换

### 硬件缺陷 (已知)
- Motor 3 (右后) 编码器损坏 — 开环
- Servo ID 3 (夹爪) — 可用
- OLED 未接 — OLED_Init 已注释
- 蓝牙未用 — BT_Init 已注释

---

## 待办 (从车对接)

### 从车硬件
- [x] 制作从车底盘 (木板/亚克力 + 2 个被动轮)
- [x] 从车前方安装 AprilTag (打印 A4 纸) — **现用 10cm×10cm 码**
- [x] 从车前方开两个槽口, 供主车夹爪伸入夹持
- [x] AprilTag ID 与主车约定一致 (ID=1, tag36h11)

### 从车对接软件
- [x] main.c 启动时先跑从车对接 (TaskQueue 第 1 步) — 已实现 dock_state 状态机 (十字路口→右拐→找码→倒车→挂钩)
- [x] 对接成功后 trailer_docked=1, 切到货物收集循环
- [x] 货物收集完毕, TaskQueue 跑终点
- [x] ACTION_HOOK 实现 (夹爪伸入从车槽口并夹紧) — Action_HookTrailer()
- [x] 视觉 PID 实机调参 (vkp/vki/vpid 命令) — **对接已改视觉伺服式**: dock_state 3 倒车用 VisualServo_TaskReverse 双 PID (横向 P-only kp=1.0 + 纵向 P-only kp=1.5, 右后轮 7% + 右前轮 15% 补偿, 距离跳变过滤, **丢码即停**) — **2026-08-24 连续 3 次 OK reached 40cm 验证通过**
- [x] AprilTag 尺寸: **已从 15cm 大码换为 10cm 码** — OpenMV TAG_W_CM=10.0 (FOCAL_TAG=282 纯焦距不变, 与码尺寸无关)

### LLM 自动调参 (从车对接完成后)
- [ ] visual_servo.c 加 CSV 遥测输出
- [ ] 跑 LLM PID Tuner 精调参数
- [ ] 录屏: LLM 自动调参过程 → 放设计报告

### 设计报告 + 答辩
- [ ] 撰写设计报告
- [ ] 答辩 PPT: 控制链路一张图 + AI 全链路 (采集→训练→量化→部署)
- [ ] 预演答辩 10 遍
- [x] 现场备用: 串口 `run`/`restart` 一键重置整流程命令 (已实现, 2026-06-23)

### 答辩应用场景（重点讲中间两个）

| 场景 | 对应能力 | 答辩策略 |
|---|---|---|
| 3C电子产线 | 巡线零成本改线 | 略提 |
| **医院物流** | 端侧AI离线可用，不依赖WiFi（医疗设备电磁干扰） | **重点展开** |
| **快递中转场** | 视觉伺服自动挂接从车，无动力拖挂成本极低 | **重点展开** |
| 危险品仓库 | 本地推理+电池供电，防爆区无布线 | 略提 |

**场景一：医院物流**
- 药品/标本配送，不能走WiFi（电磁干扰医疗设备）
- 端侧AI不依赖网络，离线可跑
- 巡线黑胶带部署灵活，不破坏医院地面
- 系统四种硬件容错策略 → 医疗场景对可靠性的高要求

**场景二：快递中转场**
- 拖挂多节笼车，人工对接费力且易出错
- 视觉伺服自动挂接从车，替代人工对接
- 十字路口检测 → 自主对接 → 拖挂运输 → 全流程无人化
- 无动力从车成本极低（木板+被动轮+AprilTag打印纸），适合大规模部署

---

## 最终演示流程 (~2.5 分钟)

```
上电
 │
 ├─ 0:00  ★ 从车对接 (开场高光)
 │        巡线 → 十字路口(5路全踩) → 停车
 │        → 旋转扫描 → 扫到从车 AprilTag (ID=1)
 │        → 旋转对准 → 直进靠近 → 夹爪伸入槽口
 │        → LED 长亮 = 挂接成功
 │        评委第一印象: 十字路口定位 + 视觉对接, 不一样
 │
 ├─ 0:30  拖着从车巡线 → 找货物 1 (红五边形)
 │        QR扫到 → AI分类 "red_hexagon 95%"
 │        → 腰座+车身对准 → 夹爪抓 → 放从车上
 │
 ├─ 1:00  货物 2 (绿圆形)
 │        冷却期后自动触发 → 同上
 │        评委看到: 循环可靠
 │
 ├─ 1:30  货物 3 (黄长方形)
 │        同上 → 从车上堆了三个货
 │
 ├─ 1:50  拖着满载从车巡线到终点
 │
 └─ 2:10  停车 → LED 三闪 = 任务完成
```

## 从车对接详细设计

### 触发: 巡线十字路口检测

利用现有 5 路巡线传感器, 十字路口时全部踩线:

```
正常巡线:                   十字路口:

  ██                         ██
  ██ ← 2-3 路踩线             ██
──██──                     ──████──
  ██                         ██
  ██                     5 路全踩 → 触发停车

LineSensor_AllOn() → TIM6 ISR 自动停车 → main loop 接管
```

### 对接: 序贯对准 (先转再直)

```
十字路口停车
    │
    ▼
OpenMV 切 APRILTAG 模式
    │
    ▼
旋转扫描: 车身原地旋转一圈找 AprilTag
    │  左轮正转 + 右轮反转 = 原地旋转
    │  扫到从车标签 (tag_id=1) → 记录
    │
    ▼
旋转对准: 比例P控制
    │  error_x = cx - target_cx
    │  turn = error_x × 3  (±400钳制)
    │  |error_x| < 15px → 对准完成
    │
    ▼
直进靠近: 比例P控制
    │  forward = (distance - target_dist) × 20  (±300钳制)
    │  distance ≤ target_dist + 3cm → 停止
    │
    ▼
停车 → 夹爪伸入从车槽口 → 挂接完成
```

> **设计决策**: 先转再直而不是双PID同时跑。现场比赛稳 > 快, 序贯方式各阶段独立调参, 互不干扰, 翻车概率几乎为零。双PID同时跑的代码保留在 visual_servo.c 作为答辩素材, 证明我们实现了两种策略并选择了更可靠的方案。

### Tag 安装: 垂直贴, 与摄像头同高

```
主车                          从车
┌──────┐                    ┌──────────┐
│      │                    │          │
│  📷  │ ← 摄像头高度 h     │  标签    │ ← 高度 = h
│      │                    │   ⬜     │
│ 夹爪 │ ←── 对接 ──→      │  槽口    │
└──────┘                    └──────────┘
```

---

## 实现方案: TaskQueue + AI Pipeline 混合调度

```
main() 启动 → 巡线出发 (OpenMV=APRILTAG)
    │
    ▼
十字路口检测 (5路全踩)
    │
    ▼
停车 → 旋转扫描 → 对准 → 夹爪进槽口 → trailer_docked=1
    │
    ▼
倒车退回巡线 → 切 OpenMV=QRCODE
    │
    ▼
AI Pipeline 货物收集 (现有 main.c Phase 0-3 循环)
    │  巡线 → QR → AI分类 → 颜色对准 → 抓取 → 放从车
    │  重复 3 次 (红→绿→黄)
    ▼
巡线到终点 → 停车 → LED 三闪
```

### 要改动的文件
| 文件 | 改动 | 工作量 |
|---|---|---|
| line_sensor.c/h | 新增 `LineSensor_AllOn()` 函数 | ~8 行 |
| Timer.c | ISR 里巡线分支加入十字检测, 自动停车 | ~8 行 |
| main.c | 十字触发后接管: 旋转扫描→对准→直进→夹取 | ~40 行 |
| main.c | 对接成功后启动 AI Pipeline | ~5 行 |
| main.c | 货物完成 → 巡线到终点 | ~5 行 |
| state_machine.c | ACTION_HOOK 实现 | ~5 行 |
| OpenMV main.py | 不改, 已支持 APRILTAG 模式 | 0 |

### 备用串口命令
```
restart  — 一键重置: 无论在哪个 phase, 直接回到巡线继续走
vpid     — 查看视觉伺服 PID 当前参数 + 对准状态
```

---

## 类别→颜色映射

| class_id | 类别 | 颜色 ID | 用途 |
|:--:|---|:--:|---|
| 0 | red_hexagon | 1 (红) | AI分类后颜色对准 |
| 1 | green_circle | 2 (绿) | |
| 2 | yellow_rect | 3 (黄) | |

## QR 码约定
| 内容 | 动作 |
|---|---|
| 包含 `GRASP` | 抓取 |
| 包含 `PLACE` | 放置 |
| 其他/空 | 默认抓取 |

---

## 答辩创新点待办 (2026-06-30)

### 🟡 中投入（答辩前做完）

#### 1. 自适应 PID — 根据从车负载自动调增益
- [ ] `Timer.c` 或 `pid.c`：根据 `trailer_cargo_count` 动态调整速度 PID 的 Kp
- [ ] 空载 vs 满载查表/线性插值（质量比 1:4 → Kp 波动 ~30%）
- [ ] 答辩说法："拖挂三个货物后整车质量变化 ~3 倍，做了负载自适应 PID"

**实现思路**：
```c
// 在 TIM6 ISR 的速度 PID 计算前
float mass_ratio = (trailer_cargo_count + 1.0f) / 4.0f;  // 0.25 ~ 1.0
float kp_adj = Kp_base * (1.0f + mass_ratio * 0.3f);
PID_SetKp(&pid_motor[i], kp_adj);
```

#### 2. 抓取成功率统计 + 可视化
- [ ] `main.c` 或 `vision_task.c`：每次抓取后记录成功/失败
- [ ] 按货物类别分别统计（红六边形/绿圆形/黄长方形）
- [ ] 串口命令 `stats` 输出统计结果
- [ ] 跑 ≥30 次实验，画柱状图放 PPT

**数据结构**：
```c
struct {
    uint16_t attempt[4];   // [0]=total, [1]=red, [2]=green, [3]=yellow
    uint16_t success[4];   // 同上
} grasp_stats;
```

#### 3. 舵机掉电策略 — 能耗量化分析
- [ ] 估算各舵机保持/运动电流（查 MG996R 或同类 datasheet）
- [ ] 测算到达目标后断电节省的功耗（已有代码，缺数据）
- [ ] PPT 上放一张对比表：持续供电 vs 智能断电的续航差异

**答辩说法**："腰座舵机保持力矩需要持续 ~300mA@6V，到达目标后断电节省 ~1.8W，三个舵机累计续航提升约 15%。"

---

### 🔴 高投入（答辩后有空做，可写进设计报告）

#### 4. AprilTag 里程计融合定位
- 赛道关键位置贴 AprilTag 作为绝对地标
- 路过时用标签位姿校正编码器里程计累积误差
- 本质是简化版 EKF/互补滤波 —— 地标辅助里程计

#### 5. 从车路径规划 — 铰接车运动学
- 拖挂从车后转弯半径变化建模（单车 → 铰接车）
- 论文/报告里放运动学公式 + 最小转弯半径推导
- 可选：倒车入库的路径规划仿真

#### 6. AI 模型鲁棒性测试 — 对抗样本实验
- 对测试图片加噪声（亮度 ±30%、旋转 ±15°、遮挡 20%）
- 测试 MobileNetV2 α=0.35 在扰动下的精度衰减曲线
- 学术界标准实验方法，图多、花钱少、放设计报告很加分

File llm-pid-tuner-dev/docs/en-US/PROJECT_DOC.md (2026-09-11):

`# LLM-PID-Tuner Project Notes

This document is for maintainers, contributors, and anyone who wants a quick understanding of the project internals.

If you just want to use the packaged build, start with [README.md](README.md).

> If you want the **latest development internals and newest tutorial entry points**, prefer the `dev` branch version of this document:  
> <https://github.com/KINGSTON-115/llm-pid-tuner/blob/dev/docs/en-US/PROJECT_DOC.md>

## 1. Project Goals

The core goal is not to produce impressive benchmark numbers. It is to:

- Use an LLM to reduce the trial-and-error cost of manual PID tuning
- Minimize "parameters spiraling out of control" situations on real hardware
- Stop tuning early once the system is usable, rather than over-optimizing
- Keep a fallback path working even when something goes wrong

In short, this project aims to be a **practical tuning assistant**, not an academic optimal control framework.

## 2. Main Components

### `tuner.py`

The main program for real hardware tuning.

Responsibilities:

- Read `config.json` and environment variables
- Scan and connect to the serial port
- Read CSV data reported by the MCU
- Compute current tuning metrics
- Call the LLM for new PID suggestions
- Apply PID guardrails, fallback logic, best-result tracking, and rollback logic

### `simulator.py`

A local thermal system simulator for validating tuning strategies without real hardware.

Responsibilities:

- Simulate the thermal inertia and heat dissipation of the plant
- Run the auto-tuning loop with logic similar to `tuner.py`
- Quickly verify whether a strategy is clearly going off the rails

### `pid_safety.py`

The centralized stability and fallback logic module.

Responsibilities:

- PID parameter guardrails
- Fallback suggestions when the LLM fails
- "Good enough" judgment
- Best-result tracking
- Rollback judgment when results deteriorate

### `firmware.cpp`

Example MCU-side firmware.

Responsibilities:

- Compute PID on a fixed time interval
- Output CSV data over serial
- Receive new PID parameters sent from the host

### `system_id.py`

A system identification utility.

Responsibilities:

- Read step-response data from serial or a CSV file
- Estimate first-order plus dead-time (FOPDT) model parameters
- Produce Ziegler-Nichols style initial PID suggestions

### `doctor.py`

An environment diagnostic and checking utility.

Responsibilities:

- Quickly validate `config.json` format and required fields
- Check serial port permissions and availability
- Test LLM API connectivity
- Detect MATLAB/Simulink environment and proxy configurations
- Output a detailed health report to help users avoid startup failures due to environment issues

### `core/i18n.py`

System language detection and internationalization support.

Responsibilities:

- Auto-detect system language (`zh` / `en`)
- Maintain global language state and support the `--lang` override argument
- Provide runtime text translation switching

### `sim/pre_tuning_dialog.py`

Interactive pre-tuning dialog module.

Responsibilities:

- Collect natural language control preferences and constraints from the user before the main tuning loop starts (e.g., "no overshoot allowed")
- Call the LLM API to extract and structure the user's preferences
- Integrate the extracted hard and soft constraints into the subsequent prompts, guiding the LLM to tune according to specific scenario requirements

### `benchmark.py`

A fixed-seed development verification tool.

Responsibilities:

- Compare `baseline` / `fallback` / `llm` paths
- Observe strategy changes in a reasonably reproducible way

This is a development utility, not the core value of the project.

## 3. Real Hardware Workflow

The overall flow is:

1. (Optional) Run `doctor.py` to diagnose environment setup before tuning
2. (Optional) In interactive mode, enter the pre-tuning dialog to set natural language constraints and preferences
3. MCU outputs process data using the `firmware.cpp` style protocol
4. `tuner.py` reads and buffers the data over serial
5. After accumulating a sampling window, compute error, overshoot, stability, and other metrics
6. Send the current summary, history, and **user-defined constraints** to the LLM
7. LLM returns new PID suggestions
8. Suggestions pass through the guardrails and validation in `pid_safety.py`
9. The program sends the new PID back to the device and enters the next round
10. If results deteriorate, roll back to the best historical result
11. If results are already good enough, keep the current PID values and enter observation rounds
12. Stop early after `REQUIRED_STABLE_ROUNDS` consecutive stable evaluations, which defaults to 3

## 4. Configuration Sources and Priority

Runtime configuration comes from two places:

- `config.json`
- Environment variables

Priority order:

1. Default values
2. `config.json`
3. Environment variable overrides (highest priority)

For beginners, `config.json` is recommended. For automated scripts, environment variables are more convenient.

## 5. Serial Protocol Convention

The project expects the MCU to output one CSV line per cycle, with fields in this order:

```text
timestamp_ms,setpoint,input,pwm,error,p,i,d
```

Field descriptions:

- `timestamp_ms`: millisecond timestamp
- `setpoint`: target value
- `input`: current measured value
- `pwm`: control output
- `error`: current error
- `p/i/d`: PID parameters currently in use

If your hardware protocol differs, the recommended approach is to align your firmware with `firmware.cpp` rather than patching the host-side code.

Hardware mode can also select a built-in protocol adapter through `HARDWARE_PROFILE`:

- `generic_serial_csv`: the default profile, using the CSV protocol above.
- `stm32f407_openmv`: STM32F407 + OpenMV text telemetry, including `Status:` snapshots, `T:x,y`, and `N`.
- `mspm0_datavision`: MSPM0 DataVision binary telemetry frames. This profile is read-only for now and does not send PID values back to hardware until a write-back protocol is confirmed.

If you do not need a special hardware protocol, keep `HARDWARE_PROFILE=generic_serial_csv`; the existing workflow stays unchanged.

## 6. Key Design Principles

### 6.1 Prefer usability over aggression

The goal is not to push parameters harder each round. Instead, the priority is:

- Gradually move the system toward a usable state
- Avoid obvious oscillation and degradation
- Preserve rollback headroom

### 6.2 The LLM is a tuning assistant, not the sole authority

LLM suggestions are valuable, but model output can be unstable. That is why the system includes:

- JSON sanitization and parse protection
- Provider / API compatibility handling
- Fallback logic
- Best-so-far tracking and memory-based rollback

### 6.3 "Good enough" matters more than chasing lower scores

In real control applications, the system often already meets the requirement. Continuing to minimize error can introduce more risk than benefit.

This is why early stopping and stable-round counting are built into the runtime. The current behavior is not "one good round and immediately stop": the runtime first checks `GOOD_ENOUGH_AVG_ERROR`, `GOOD_ENOUGH_STEADY_STATE_ERROR`, and `GOOD_ENOUGH_OVERSHOOT`; once a round is good enough, it keeps the current PID values and observes subsequent rounds instead of requesting a new LLM suggestion. It stops after `REQUIRED_STABLE_ROUNDS` consecutive stable evaluations, which defaults to 3. If the response gets worse during observation, the stable counter resets and normal LLM tuning resumes.

## 7. Packaging Notes

The Windows executable is built with `PyInstaller`, with `launcher.py` as the entry point.

`launcher.py` dispatches the packaged build into two user-facing paths:

- `tuner.py` for real hardware tuning
- `simulator.py` for the local simulation / TUI

The current release strategy is designed for end users:

- Source code stays for developers
- The `exe` is for users who want to run directly

## 8. Recommended Maintenance Principles

When evolving the project, maintain these principles:

- Every piece of logic should have a clear purpose
- Fix root causes; do not pile on surface patches
- Do not sacrifice real-world usability for better benchmark scores
- Do not add heavy layers with low practical value
- Keep the real hardware tuning pipeline stable as the top priority

## 9. Entry Points for New Users

If you are handing this project to someone unfamiliar with Python, PID, or serial communication, direct them to:

- [README.md](README.md)
- [RELEASE_NOTES.md](RELEASE_NOTES.md)

Both documents are written in the order: download the exe first, then configure, then connect hardware.

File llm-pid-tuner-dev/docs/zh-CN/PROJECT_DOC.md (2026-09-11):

# LLM-PID-Tuner 项目说明

这份文档面向维护者、二次开发者，以及想快速理解项目内部结构的人。

如果你只是想直接使用打包版，请先看 [README.md](../../README.md)。

> 如果你想看 **最新开发版的内部结构和最新教程入口**，请优先看 `dev` 分支版本：  
> <https://github.com/KINGSTON-115/llm-pid-tuner/blob/dev/docs/zh-CN/PROJECT_DOC.md>

## 1. 项目目标

本项目的核心目标不是跑出好看的 benchmark，而是：

- 用 LLM 帮用户减少 PID 手工整定的试错成本
- 在真实硬件上尽量减少“参数越调越离谱”的情况
- 让系统在可用后尽量早点停，而不是过度调参
- 出现异常时仍然保留一条可继续工作的保底路径

换句话说，项目更偏向“**可落地的调参助手**”，而不是“学术型最优控制框架”。

## 2. 主要组件

### `tuner.py`

真实硬件调参主程序。

职责：

- 读取 `config.json` / 环境变量
- 扫描并连接串口
- 读取 MCU 上报的 CSV 数据
- 计算当前调参指标
- 调用 LLM 获取新的 PID 建议
- 应用 PID 护栏、保底逻辑、最佳结果记录和回退逻辑

### `simulator.py`

本地热系统仿真器，用来验证调参策略，不依赖真实硬件。

职责：

- 模拟被控对象的热惯性和散热过程
- 用与 `tuner.py` 类似的逻辑跑自动调参
- 便于快速验证策略是否明显跑偏

### `pid_safety.py`

稳定性与保底逻辑集中模块。

职责：

- PID 参数护栏
- LLM 失效时的 fallback 建议
- “已经够好”判断
- 最佳结果记录
- 结果恶化时的回退判断

### `firmware.cpp`

单片机侧示例固件。

职责：

- 按固定周期计算 PID
- 通过串口输出 CSV 数据
- 接收上位机下发的新 PID 参数

### `system_id.py`

系统辨识辅助工具。

职责：

- 读取串口或 CSV 文件中的阶跃响应数据
- 估计一阶惯性 + 纯滞后近似参数
- 给出 Ziegler-Nichols 风格的初始 PID 建议

### `doctor.py`

环境诊断与检查工具。

职责：

- 快速验证 `config.json` 格式及必填字段
- 检查串口权限及占用情况
- 测试 LLM API 连通性
- 检测 MATLAB/Simulink 环境及代理配置
- 为用户输出详细的环境体检报告，避免因环境问题带来的启动失败

### `core/i18n.py`

系统语言检测与多语言支持。

职责：

- 自动检测系统语言 (`zh` / `en`)
- 维护全局语言状态，支持启动参数 `--lang` 强制覆盖
- 提供运行时的文本翻译切换机制

### `sim/pre_tuning_dialog.py`

交互式预调参对话模块。

职责：

- 在主调参循环前，向用户收集自然语言描述的控制偏好与约束（例如“不能超调”）
- 调用 LLM 接口，将用户输入的偏好提取并结构化
- 将提取出的硬性与软性约束融合到后续的提示词中，指导 LLM 贴合特定场景进行调参

### `benchmark.py`

固定随机种子的开发验证工具。

职责：

- 对比 `baseline` / `fallback` / `llm` 三条路径
- 用较可复现的方式观察策略变化

它是开发辅助工具，不是项目的核心价值本身。

## 3. 真实硬件工作流

整体流程如下：

1. （可选）启动前，通过 `doctor.py` 诊断环境配置
2. （可选）如果允许交互，进入预调参对话，接收用户的自然语言约束条件
3. MCU 使用 `firmware.cpp` 风格协议输出过程数据
4. `tuner.py` 通过串口读取并缓存数据
5. 累积到一定采样窗口后，计算误差、超调、稳定性等指标
6. 把当前摘要、历史结果及用户的**预设约束**发给 LLM
7. LLM 返回新的 PID 建议
8. 建议先经过 `pid_safety.py` 的护栏与校验
9. 程序把新 PID 发回设备，进入下一轮
10. 如果结果恶化，优先回退到历史最佳结果
11. 如果结果已经够好，先保持当前 PID 进入观察轮
12. 连续稳定达到 `REQUIRED_STABLE_ROUNDS` 后提前停止，默认 3 轮

## 4. 配置来源与优先级

运行时配置主要来自两个地方：

- `config.json`
- 环境变量

优先级：

1. 默认配置
2. `config.json`
3. 环境变量覆盖

也就是说，环境变量优先级最高。

对小白来说，推荐使用 `config.json`；对自动化脚本来说，环境变量更方便。

## 5. 串口协议约定

当前项目默认 MCU 输出一行 CSV，字段顺序为：

```text
timestamp_ms,setpoint,input,pwm,error,p,i,d
```

其中：

- `timestamp_ms`：毫秒时间戳
- `setpoint`：设定值
- `input`：当前测量值
- `pwm`：控制输出
- `error`：误差
- `p/i/d`：当前使用的 PID 参数

如果你的硬件协议和这个不一致，优先建议从 `firmware.cpp` 同步，而不是在上位机里临时打补丁。

硬件模式还支持通过 `HARDWARE_PROFILE` 选择内置协议适配器：

- `generic_serial_csv`：默认值，继续使用上面的 CSV 协议。
- `stm32f407_openmv`：适配 STM32F407 + OpenMV 文本遥测，包括 `Status:` 快照、`T:x,y` 和 `N`。
- `mspm0_datavision`：适配 MSPM0 DataVision 二进制遥测帧。当前为只读遥测模式，在确认写回协议前不会向硬件发送 PID 参数。

如果没有特殊硬件协议需求，请保持 `HARDWARE_PROFILE=generic_serial_csv`，这样原有使用方式不变。

## 6. 关键设计取向

### 6.1 优先可用，而不是盲目激进

项目不是要求每一轮都把参数改得更猛，而是优先：

- 让系统逐步逼近可用状态
- 尽量避免明显震荡和劣化
- 保留回退空间

### 6.2 LLM 是调参助手，不是唯一真理

LLM 的建议很有价值，但模型输出可能不稳定，因此需要：

- JSON 清洗与解析保护
- provider / API 兼容处理
- fallback 逻辑
- best-so-far 和记忆回退

### 6.3 “已经够好”比“继续追分”更重要

在真实控制里，很多时候系统已经满足需求。
继续追求极小误差，可能反而带来更大风险。

因此运行时加入了提前停止和稳定轮次判断。当前逻辑不是“单轮达标立刻结束”，而是先用 `GOOD_ENOUGH_AVG_ERROR`、`GOOD_ENOUGH_STEADY_STATE_ERROR` 和 `GOOD_ENOUGH_OVERSHOOT` 判断本轮是否够好；够好后保持当前 PID 继续观察，不再请求 LLM 给出新参数。连续 `REQUIRED_STABLE_ROUNDS` 轮稳定后停止，默认值是 3。如果观察阶段变差，稳定计数会重置，系统回到正常 LLM 调参流程。

## 7. 打包说明

Windows 可执行文件由 `PyInstaller` 打包生成，入口是 `launcher.py`。

`launcher.py` 会在启动时分流到两条路径：

- `tuner.py`：真实硬件调参
- `simulator.py`：本地仿真 / TUI

当前发布策略更适合面向终端用户：

- 源码保留给开发者
- `exe` 保留给直接使用者

## 8. 推荐维护原则

后续继续演进时，优先保持这几条原则：

- 每一段逻辑都要有明确目的
- 优先修根因，不堆表面补丁
- 不为了“跑分更好看”牺牲真实可用性
- 不新增体积庞大但价值不高的复杂层
- 优先保证真实硬件调参链路稳定

## 9. 新手文档入口

如果你要把项目交给不熟悉 Python / PID / 串口的人，请优先让对方看：

- [README.md](../../README.md)
- [RELEASE_NOTES.md](RELEASE_NOTES.md)

这两份文档已经按“先下载 exe，再配置，再连接硬件”的顺序写好了。

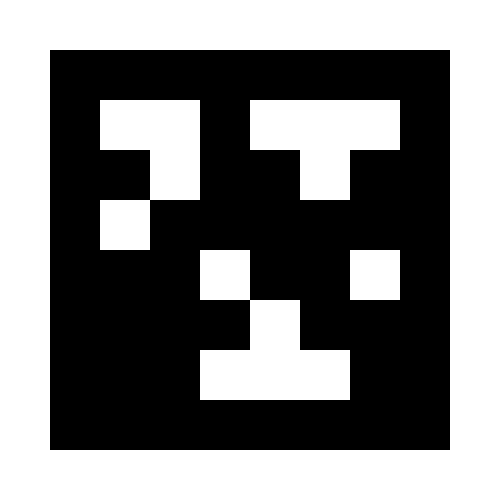
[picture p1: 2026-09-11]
apriltags/tag36h11_id2_30mm.png

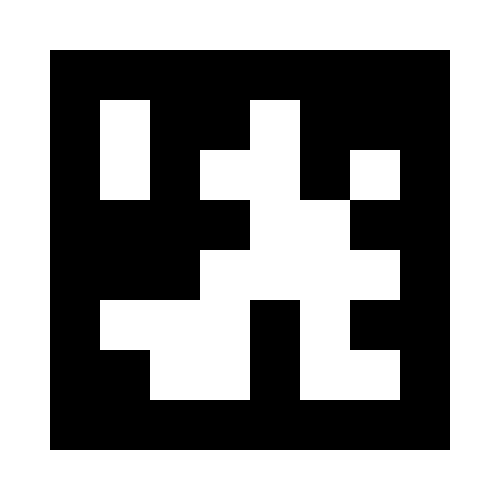
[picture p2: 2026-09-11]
从车对接_apriltag/tag36h11_ID1_50mm.png

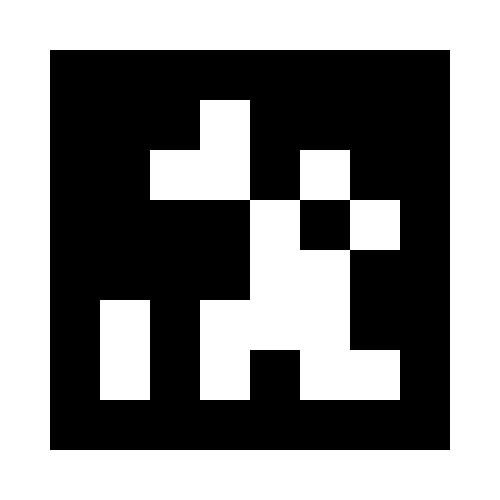
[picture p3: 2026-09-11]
从车对接_apriltag/tag36h11_id0_50mm.png

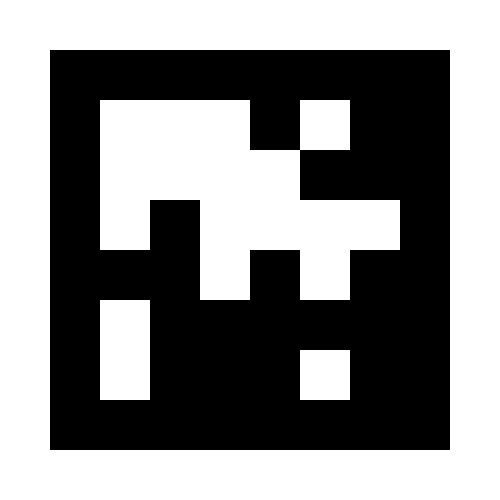
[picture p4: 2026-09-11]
apriltags/tag36h11_id4_30mm.png

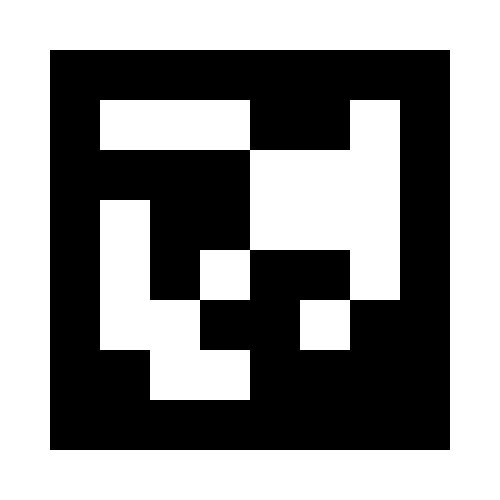
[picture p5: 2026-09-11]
apriltags/tag36h11_id3_30mm.png

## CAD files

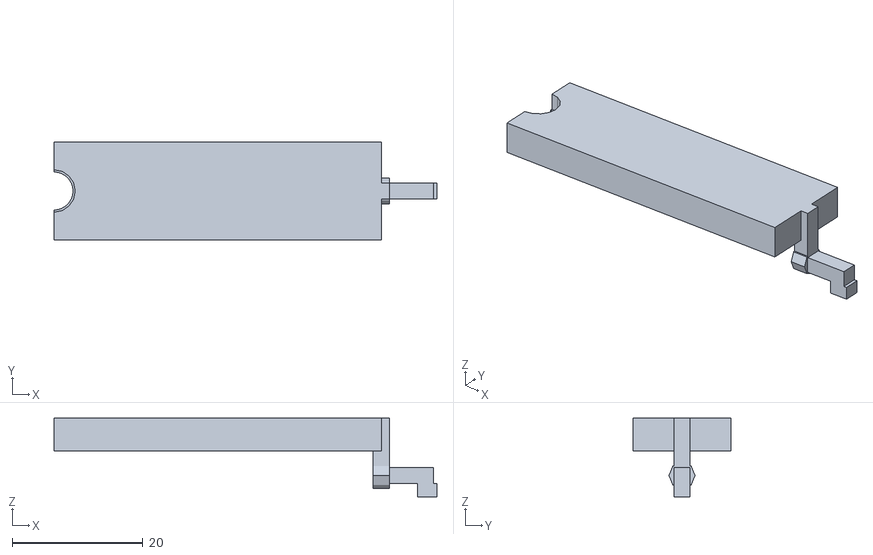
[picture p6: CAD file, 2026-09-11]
hardware/hook/hook.stl
58.5 x 15.0 x 12.0

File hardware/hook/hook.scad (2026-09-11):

// 挂钩舵机钩子 — MG996R 直驱
// OpenSCAD 打开此文件 → F6 渲染 → Export STL
// 单位: mm

/* ===== 可调参数 ===== */
HOOK_LENGTH    = 50;    // 钩身总长 (舵机轴心→钩尖)
HOOK_WIDTH     = 15;    // 钩身宽度
HOOK_THICK     = 5;     // 钩身厚度 (平放打印)
TIP_DROP       = 10;    // 钩头下探 (Z轴高低差)
TIP_WIDTH      = 2.5;   // 钩尖宽度 (适配3~4mm从车槽口)
TIP_LENGTH     = 8;     // 钩尖长度 (伸入槽口部分)
CURVE_R        = 5;     // 过渡圆弧半径
SHAFT_DIAM     = 5.8;   // 中心孔径 (略小于舵机轴6mm, 压入咬紧)
SCREW_DIAM     = 3.2;   // M3沉头螺丝孔
SCREW_HEAD_DIAM = 6.5;  // M3沉头直径
SCREW_HEAD_DEPTH = 2.5; // M3沉头深度
$fn            = 64;    // 圆弧精度

/* ===== 主模型 ===== */
module hook() {
    difference() {
        union() {
            // —— 钩身平板 ——
            // 舵机轴心在原点，钩子沿 +X 方向伸出
            translate([HOOK_LENGTH/2, 0, 0])
                cube([HOOK_LENGTH, HOOK_WIDTH, HOOK_THICK], center=true);

            // —— 弧形过渡 (宽度渐变: 15→2.5) ——
            // 用 hull() 连接钩身末端和钩尖起点的椭圆截面
            hull() {
                // 钩身末端 (宽15, 厚5)
                translate([HOOK_LENGTH - CURVE_R, 0, HOOK_THICK/2])
                    cube([0.1, HOOK_WIDTH, HOOK_THICK], center=true);
                // 钩尖起点 (宽2.5, 厚5, 下探开始)
                translate([HOOK_LENGTH, 0, HOOK_THICK/2])
                    cube([0.1, TIP_WIDTH, HOOK_THICK], center=true);
            }

            // —— 钩尖下探 (垂直柱) ——
            translate([HOOK_LENGTH, 0, -TIP_DROP/2 + HOOK_THICK/2])
                cube([TIP_WIDTH, TIP_WIDTH, TIP_DROP - HOOK_THICK/2], center=true);

            // —— 钩尖水平段 (伸入槽口的部分) ——
            translate([HOOK_LENGTH + TIP_LENGTH/2, 0, -TIP_DROP + HOOK_THICK/2 + TIP_WIDTH/2])
                cube([TIP_LENGTH, TIP_WIDTH, TIP_WIDTH], center=true);

            // —— 钩尖回钩 (防滑脱的小倒钩) ——
            translate([HOOK_LENGTH + TIP_LENGTH - 1, 0, -TIP_DROP + HOOK_THICK/2 - 0.5])
                rotate([0, 30, 0])
                    cube([3, TIP_WIDTH, TIP_WIDTH], center=true);
        }

        // —— 中心孔 (舵机轴 φ5.8mm) ——
        translate([0, 0, -1])
            cylinder(d=SHAFT_DIAM, h=HOOK_THICK + 2);

        // —— M3 沉头螺丝孔 (从上表面贯穿) ——
        translate([0, 0, HOOK_THICK - SCREW_HEAD_DEPTH])
            cylinder(d=SCREW_HEAD_DIAM, h=SCREW_HEAD_DEPTH + 0.1);
        translate([0, 0, -1])
            cylinder(d=SCREW_DIAM, h=HOOK_THICK + 2);

        // —— 减重槽 (可选, 勾身中间挖空) ——
        translate([HOOK_LENGTH * 0.45, 0, HOOK_THICK/2])
            cube([HOOK_LENGTH * 0.5, HOOK_WIDTH - 6, HOOK_THICK + 1], center=true);
    }
}

// 渲染
hook();

/* ===== 打印说明 =====
 * 摆放: 平放在热床上 (钩身水平, 钩尖朝上悬空)
 *       Z轴层纹垂直于钩身 → 强度最优
 * 支撑: 钩尖下探10mm悬空 → 必须开支撑 (树状支撑, 仅接触热床)
 * 材料: PLA 或 PETG (PETG韧性更好)
 * 填充: 100% (实心)
 * 壁厚: 至少3层 (0.4mm喷嘴 = 1.2mm壁厚)
 */

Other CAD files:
hardware/hook/hook.dxf

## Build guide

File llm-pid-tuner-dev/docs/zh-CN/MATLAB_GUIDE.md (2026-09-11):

# MATLAB/Simulink 仿真调参指南

本文档说明如何使用 llm-pid-tuner 对 MATLAB/Simulink 模型进行 **AI 调参**。

这份指南重点覆盖三类情况：

1. **标准单个 PID/PI/PD/P 控制器块**
2. **双控制器 / 主副环（例如 cascade）**
3. **分离式 P/I/D 增益块**

如果你只是想快速跑通，先按“标准单个控制器块”配置即可；如果你的模型更复杂，再逐步切到双控制器或分离增益块配置。

---

## 快速开始（下载 exe，零代码运行）

如果你不想配置 Python 环境，直接下载打包好的 exe 即可：

1. 从 Releases 页面下载最新的 `llm-pid-tuner.exe`
2. 将 `llm-pid-tuner.exe` 和同目录的 `config.json` 放在同一个文件夹里
3. 编辑 `config.json`，填入你的 LLM API Key 和 Simulink 相关配置（详见下文）
4. 双击运行 `llm-pid-tuner.exe`，或在终端中执行：

   ```bash
   llm-pid-tuner.exe
   ```

5. 在菜单中选择「Simulink 仿真调参」
6. 调参完成后按 Enter 退出，结果会保存回 `.slx` 文件

> **前提**：你的电脑上需要已安装并激活 MATLAB。打包版不会替代本机 MATLAB 许可证。

---

## 这个模式适合什么场景

- 你已经在 Simulink 里搭好了控制对象，想快速找一组能用的参数
- 你的系统不是简单单环，有主副环、双控制器或分离式增益块
- 你想在上真实硬件之前，先在仿真里把参数收敛到合理范围
- 你的模型里控制器参数命名不是标准 `P/I/D`，而是 `Kp/Ki/Kd` 或 `ProportionalGain/IntegralGain/DerivativeGain`
- 你希望程序尽量少改模型结构，而是直接适配现有 Simulink 工程

---

## 它是怎么工作的

```text
Simulink 模型  ──同步运行一轮仿真──>  输出时间序列（To Workspace）
                                              │
                                  提取 Time / Data 数组，计算误差、超调、稳态误差
                                              │
                                  LLM 分析本轮数据 + 历史记录，给出新参数建议
                                              │
                     写回一个或多个控制器块（或分离式 P/I/D 增益块）
                                              │
                                  继续下一轮仿真 ──> 收敛
```

每轮仿真都从初始状态重新运行，LLM 看到的时间序列单位是 **仿真毫秒（SimTime ms）**，不是真实世界时间。

---

## 第 1 步：安装 MATLAB Engine API for Python

这一步只需要做一次。MATLAB R2021b 及以上版本自带这个包，去 MATLAB 安装目录下执行：

```bash
cd <MATLAB_ROOT>/extern/engines/python
python setup.py install
```

Windows 示例路径（根据你的 MATLAB 版本替换）：

```text
D:/Program Files/MATLAB/R2025b/extern/engines/python
```

安装完成后可以验证一下：

```bash
python -c "import matlab.engine; print('OK')"
```

---

## 第 2 步：准备你的 Simulink 模型

### 先记住一个通用技巧：怎么找块路径

`MATLAB_PID_BLOCK_PATH`、`MATLAB_PID_BLOCK_PATH_2`、`MATLAB_SETPOINT_BLOCK`、`MATLAB_P/I/D_BLOCK_PATH(_2)` 本质上都在填 **Simulink 块的完整路径**。

找法统一：

1. 在 Simulink 里点击你要填写的那个块
2. 在 MATLAB Command Window 输入：

   ```matlab
   gcb
   ```

3. 把返回的字符串原样复制到 `config.json`

例如，如果 `gcb` 返回：

```text
pid_tuner/Inner Loop/PID Controller
```

那就直接填到对应字段里，不需要自己手动拼路径。

如果块在子系统里，返回路径会自动包含层级。

### 必需项 1：输出信号

把你想调的被控量接到一个 To Workspace 块，然后按以下步骤配置：

1. 双击 To Workspace 块
2. **Variable name**：填变量名，例如 `y_out`
3. **Save format**：推荐 `Timeseries`
4. **Sample time**：填 `-1`（继承模型步长）或与模型步长一致
5. 点击 OK 保存

手动验证：

```matlab
sim('your_model_name');
whos y_out
```

如果你模型里输出变量名不稳定，也可以后面在 `config.json` 里用 `MATLAB_OUTPUT_SIGNAL_CANDIDATES` 提供一组候选名。

### 必需项 2：控制器参数必须能被写回

程序当前支持三种常见结构：

#### 方案 A：标准单个控制器块

最推荐。比如标准 `PID Controller`、`PI Controller`、`PD Controller`、`P Controller`。

常见可兼容参数名：

- `P` / `I` / `D`
- `Kp` / `Ki` / `Kd`
- `P_Gain` / `I_Gain` / `D_Gain`
- `ProportionalGain` / `IntegralGain` / `DerivativeGain`

#### 方案 B：双控制器 / 主副环

例如：

- `Outer PID`
- `Inner PID`

程序会分别向两组控制器写参数。这个支持目前属于**最小可用**：推荐你显式填写两组路径，不要完全依赖自动识别。

#### 方案 C：分离式 P/I/D 增益块

如果你的控制器不是单个 PID block，而是自己拼出来的结构，也可以：

- 单独给 P 块路径
- 单独给 I 块路径
- 单独给 D 块路径

程序会分别写这些块的 `Gain / Value / K / Coefficient` 之类参数。

### 建议项：设定值块

如果你的设定值来源很明确，建议直接记下它的块路径，后面填到 `MATLAB_SETPOINT_BLOCK`。

这样比完全依赖自动识别更稳。

### 建议项：控制输出信号

如果你愿意把控制器输出（例如 `u_out`）也导到 To Workspace，建议后面填到 `MATLAB_CONTROL_SIGNAL`。

这样程序就不只能看到占位 `PWM=0.0`，而是能看到真实控制输出，对调参更有帮助。

---

## 第 3 步：配置 `config.json`

### 最小单控制器配置

```json
{
  "LLM_API_KEY": "你的key",
  "LLM_API_BASE_URL": "https://api.openai.com/v1",
  "LLM_MODEL_NAME": "gpt-4o",
  "LLM_PROVIDER": "openai",

  "MATLAB_MODEL_PATH": "C:/models/my_pid_model.slx",
  "MATLAB_PID_BLOCK_PATH": "my_pid_model/PID Controller",
  "MATLAB_ROOT": "D:/Program Files/MATLAB/R2025b",
  "MATLAB_OUTPUT_SIGNAL": "y_out",
  "MATLAB_SIM_STEP_TIME": 10.0,
  "MATLAB_SETPOINT": 200.0
}
```

### 字段说明

| 字段 | 说明 | 填写示例 |
| :--- | :--- | :--- |
| `MATLAB_MODEL_PATH` | Simulink `.slx` 文件完整路径 | `C:/models/my_model.slx` |
| `MATLAB_PID_BLOCK_PATH` | 主控制器块完整路径 | `my_model/PID Controller` |
| `MATLAB_ROOT` | MATLAB 安装根目录 | `D:/Program Files/MATLAB/R2025b` |
| `MATLAB_OUTPUT_SIGNAL` | To Workspace 输出变量名 | `y_out` |
| `MATLAB_SIM_STEP_TIME` | 每轮调参运行的仿真时长（仿真秒数） | `10.0` |
| `MATLAB_SETPOINT` | 调参目标值 | `200.0` |

### 新增兼容字段

| 字段 | 什么时候用 | 说明 |
| :--- | :--- | :--- |
| `MATLAB_OUTPUT_SIGNAL_CANDIDATES` | 输出变量名不统一时 | 给一组候选输出名，程序按顺序尝试 |
| `MATLAB_CONTROL_SIGNAL` | 想让程序看到真实控制输出时 | 例如 `u_out` |
| `MATLAB_SETPOINT_BLOCK` | 自动识别设定值块不稳定时 | 显式指定 setpoint 源块 |
| `MATLAB_PID_BLOCK_PATHS` | 你有多个候选控制器块时 | 作为候选控制器路径列表 |
| `MATLAB_PID_BLOCK_PATH_2` | 双控制器 / 主副环时 | 第二组控制器块 |
| `MATLAB_P_BLOCK_PATH` `MATLAB_I_BLOCK_PATH` `MATLAB_D_BLOCK_PATH` | 控制器不是单块 PID，而是分离式增益块时 | 分别指定 P/I/D 块 |
| `MATLAB_P_BLOCK_PATH_2` `MATLAB_I_BLOCK_PATH_2` `MATLAB_D_BLOCK_PATH_2` | 第二组分离式增益块时 | 用于双控制器 |

---

### 这些字段怎么选最不容易乱

- 不带后缀的字段就是第一组 / 主控制器；带 `_2` 的字段就是第二组控制器
- 你已经知道准确块路径时，优先填 `MATLAB_PID_BLOCK_PATH`、`MATLAB_PID_BLOCK_PATH_2`、`MATLAB_SETPOINT_BLOCK`、`MATLAB_P/I/D_BLOCK_PATH`
- 你还不确定主控制器到底是哪一个，但能列出几条候选路径时，再填 `MATLAB_PID_BLOCK_PATHS`
- 自动识别是兜底方案，不建议把它当主要配置方式
- `MATLAB_CONTROL_SIGNAL` 和 `MATLAB_SETPOINT_BLOCK` 是推荐增强项，不是第一次跑通时的硬性必填

---

## 推荐填写方式（从最小配置逐步增强）

### 方案 A：标准单个 PID Controller（最简单）

下面这个示例是在“最小单控制器配置”的基础上，再加上推荐但可选的 `MATLAB_CONTROL_SIGNAL` 和 `MATLAB_SETPOINT_BLOCK`。

```json
{
  "MATLAB_MODEL_PATH": "C:/models/pid_tuner.slx",
  "MATLAB_PID_BLOCK_PATH": "pid_tuner/PID Controller",
  "MATLAB_ROOT": "D:/Program Files/MATLAB/R2025b",
  "MATLAB_OUTPUT_SIGNAL": "y_out",
  "MATLAB_CONTROL_SIGNAL": "u_out",
  "MATLAB_SETPOINT_BLOCK": "pid_tuner/Constant",
  "MATLAB_SIM_STEP_TIME": 15.0,
  "MATLAB_SETPOINT": 100.0
}
```

### 方案 B：双控制器 / 主副环

```json
{
  "MATLAB_MODEL_PATH": "C:/models/cascade_pid.slx",
  "MATLAB_PID_BLOCK_PATH": "cascade_pid/Outer PID",
  "MATLAB_PID_BLOCK_PATH_2": "cascade_pid/Inner PID",
  "MATLAB_ROOT": "D:/Program Files/MATLAB/R2025b",
  "MATLAB_OUTPUT_SIGNAL": "y_out",
  "MATLAB_CONTROL_SIGNAL": "u_out",
  "MATLAB_SETPOINT_BLOCK": "cascade_pid/Setpoint",
  "MATLAB_SIM_STEP_TIME": 10.0,
  "MATLAB_SETPOINT": 100.0
}
```

### 方案 C：分离式 P/I/D 增益块

```json
{
  "MATLAB_MODEL_PATH": "C:/models/split_pid.slx",
  "MATLAB_P_BLOCK_PATH": "split_pid/P Gain",
  "MATLAB_I_BLOCK_PATH": "split_pid/I Gain",
  "MATLAB_D_BLOCK_PATH": "split_pid/D Gain",
  "MATLAB_ROOT": "D:/Program Files/MATLAB/R2025b",
  "MATLAB_OUTPUT_SIGNAL": "y_out",
  "MATLAB_CONTROL_SIGNAL": "u_out",
  "MATLAB_SETPOINT_BLOCK": "split_pid/Setpoint",
  "MATLAB_SIM_STEP_TIME": 10.0,
  "MATLAB_SETPOINT": 100.0
}
```

### 方案 D：不想精确找块，先给候选路径

```json
{
  "MATLAB_MODEL_PATH": "C:/models/multi_loop.slx",
  "MATLAB_PID_BLOCK_PATHS": [
    "multi_loop/Outer PID",
    "multi_loop/Inner PID",
    "multi_loop/Backup Controller"
  ],
  "MATLAB_ROOT": "D:/Program Files/MATLAB/R2025b",
  "MATLAB_OUTPUT_SIGNAL": "y_out",
  "MATLAB_OUTPUT_SIGNAL_CANDIDATES": ["y_out", "yout", "plant_y"],
  "MATLAB_SIM_STEP_TIME": 10.0,
  "MATLAB_SETPOINT": 100.0
}
```

如果方案 D 能跑通，建议下一步把程序最终识别到的主控制器路径改回显式的 `MATLAB_PID_BLOCK_PATH`，这样后续会更稳。

---

## 自动识别现在能做什么

新版程序启动时会尽量打印一份识别摘要，例如：

- 主控制器块路径
- 第二控制器块路径（如果有）
- setpoint 块
- 输出信号
- 控制信号

它的作用是：

1. 帮你确认程序到底拿到了哪个控制器块
2. 出问题时更容易判断是“路径填错”还是“模型结构不兼容”

> **重要**：自动识别是 best-effort，不是万能识别。复杂模型下，推荐你显式填好主控制器路径、第二控制器路径和 setpoint 块路径。

---

## 使用复杂配置时的建议

如果你是第一次接 Simulink 调参，建议按下面顺序来：

1. **先用方案 A 跑通单控制器**
2. 再加 `MATLAB_CONTROL_SIGNAL`，让程序看到真实控制输出
3. 如果是多环，再补 `MATLAB_PID_BLOCK_PATH_2`
4. 如果不是标准 PID Controller，而是自己拼的结构，再改成分离式 `MATLAB_P/I/D_BLOCK_PATH`

不要一开始把所有高级字段全填上。最稳的思路是：

**先最小可用，再逐步增加兼容字段。**

---

## 第 4 步：运行

### 方式一：通过 launcher（推荐）

```bash
llm-pid-tuner.exe
```

在菜单中选择「Simulink 仿真调参」，程序会：
1. **执行环境诊断**：自动调用内部的 `doctor.py` 逻辑，检查 MATLAB Engine 是否可用、配置字段是否完整。
2. **预调参对话**（交互模式下）：你可以用自然语言输入调参偏好（如“超调不能超过 5%”）。
3. **启动仿真调参**：自动启动 MATLAB Engine、加载模型并开始调参。调参完成后按 Enter 退出，最终 PID 参数会自动保存回 `.slx` 文件。

### 方式二：直接调用 simulator

```bash
python simulator.py
```

`MATLAB_MODEL_PATH` 填了值，程序会自动切换到 Simulink 模式，无需额外参数。
如果你想强制使用英文界面，可以带上语言参数：
```bash
python simulator.py --lang en
```

---

## 调参策略说明

LLM 仍然采用标准的三阶段调参顺序：

### 阶段一：单独整定 P
- 保持 I 接近 0、D = 0，只调整 P
- 大步提升 P，快速找到响应速度满意且超调 < 5% 的 P 区间

### 阶段二：引入 I 消除稳态误差
- P 稳定后才开始加 I
- I 从小到大，直到稳态误差趋近于零
- 若加 I 后出现超调或振荡，说明 I 过大，需减小

### 阶段三：必要时引入 D 抑制超调
- 仅当 P+I 组合仍有明显超调或振荡时才引入 D
- D 从小值开始，D 过大会导致响应变慢（过度阻尼）
- 若 P+I 已满足要求，D 保持 0

> **注意**：每轮仿真时间序列中的 `SimTime(ms)` 是仿真时间（毫秒），不是真实世界时间。

---

## 常见问题

### Q：提示 `No module named matlab.engine`

说明 MATLAB Engine API 还没装，按第 1 步操作。注意要用安装项目依赖的**同一个 Python 环境**执行 `setup.py install`。

### Q：提示 `MATLAB 连接失败` 或启动超时

- 检查 MATLAB 是否已激活（License 有效）
- 检查 `MATLAB_MODEL_PATH` 路径是否正确，用正斜杠 `/` 或双反斜杠 `\\`
- 检查 `MATLAB_ROOT` 是否填写正确
- MATLAB Engine 首次启动较慢（30～60 秒），属正常现象

### Q：To Workspace 读不到数据

- 确认 To Workspace 模块的 Save format 设为 **`Timeseries`**
- 确认变量名与 `MATLAB_OUTPUT_SIGNAL` 完全一致
- 如果模型输出变量名不统一，可以用 `MATLAB_OUTPUT_SIGNAL_CANDIDATES` 提供候选名列表
- 确认模型在 MATLAB 里手动运行一次后工作区里有这个变量

### Q：我的模型不是单个标准 PID Controller，能调吗？

可以，按复杂度从低到高有三种方式：

1. **标准单控制器块**：只填 `MATLAB_PID_BLOCK_PATH`
2. **双控制器 / 多环**：再补 `MATLAB_PID_BLOCK_PATH_2`
3. **分离式 P/I/D 块**：改填 `MATLAB_P/I/D_BLOCK_PATH`（以及第二组 `_2` 字段）

如果你还不确定到底该填哪个，先从单控制器路径开始，跑通后再加复杂字段。

### Q：程序自动识别到了奇怪的块，怎么办？

自动识别只是兜底方案。遇到复杂模型时，建议：

- 先在 Simulink 里选中正确的块，然后用 `gcb` 拿到完整路径
- 显式填写 `MATLAB_PID_BLOCK_PATH`
- 显式填写 `MATLAB_SETPOINT_BLOCK`
- 如果是双控制器，再显式填写 `MATLAB_PID_BLOCK_PATH_2`

这样最稳。

### Q：每轮调参很慢

`MATLAB_SIM_STEP_TIME` 控制每轮仿真时长（仿真秒数）。适当减小可加快迭代速度，但需保证每轮能采集到足够反映系统响应（上升、稳态）的完整数据。一般建议设为系统响应时间常数的 3～5 倍。

### Q：Simulink 调参什么时候会自动停止？

Simulink plain 模式和 TUI 模式使用同一套停止逻辑。某轮评测满足 `GOOD_ENOUGH_AVG_ERROR`、`GOOD_ENOUGH_STEADY_STATE_ERROR` 和 `GOOD_ENOUGH_OVERSHOOT` 后，程序会保持当前 PID 参数继续观察，不再请求 LLM 生成新参数。连续 `REQUIRED_STABLE_ROUNDS` 轮评测稳定后停止，默认是 3 轮；如果观察中响应变差，会清零稳定计数并恢复正常调参。

### Q：调参结束后 PID 参数保存到哪里了？

程序在调参完成（或用户中断）时，会把当前最优 PID 参数写回 `.slx` 文件并保存。下次在 MATLAB 中打开该模型，控制器块中的参数即为调参结果。

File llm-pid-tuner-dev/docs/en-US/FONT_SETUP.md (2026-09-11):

# Font Setup

The TUI works with any monospace font, but **JetBrains Mono Nerd Font** enables
the full icon set and is bundled in the `font/` directory.

## Option 1 — Install the bundled font

1. Open the `font/` folder in the project root.
2. Right-click `JetBrainsMonoNerdFont-Regular.ttf` → **Install for all users**.

## Option 2 — Download from the website

Visit https://www.nerdfonts.com/font-downloads, search for
**JetBrainsMono**, download the zip, extract it, and install the `.ttf` files
the same way.

## Configure your terminal

| Terminal | Path |
|---|---|
| **Windows Terminal** | Settings → Profile → Appearance → Font face → `JetBrainsMono Nerd Font Mono` |
| **VS Code integrated terminal** | `terminal.integrated.fontFamily`: `"JetBrainsMono Nerd Font Mono"` |
| **Other terminals** | Set the font in the terminal's own preferences to the installed font name |

Restart the terminal after changing the font.

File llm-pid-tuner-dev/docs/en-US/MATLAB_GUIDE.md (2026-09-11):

# MATLAB/Simulink Simulation Tuning Guide

This guide explains how to use llm-pid-tuner to tune MATLAB/Simulink models with AI assistance.

It focuses on three common scenarios:

1. Standard single PID/PI/PD/P controller blocks
2. Dual-controller / cascade setups
3. Split P/I/D gain blocks

If you only want to get your first run working, start with the standard single-controller setup. If your model is more complex, add the advanced fields step by step.

---

## Quick Start (download the exe, no Python required)

If you do not want to set up a Python environment, just download the pre-built exe:

1. Download the latest `llm-pid-tuner.exe` from the Releases page
2. Put `llm-pid-tuner.exe` and `config.json` in the same folder
3. Edit `config.json` and fill in your LLM API key plus the Simulink settings described below
4. Double-click `llm-pid-tuner.exe`, or run it from a terminal:

   ```bash
   llm-pid-tuner.exe
   ```

5. Choose "Simulink simulation tuning" from the menu
6. Press Enter when tuning finishes; the tuned values are saved back to the `.slx` file

> **Prerequisite:** MATLAB must already be installed and licensed on your machine. The packaged app does not replace a local MATLAB installation or license.

---

## When to use this mode

- You already have a Simulink plant model and want a usable parameter set quickly
- Your system is not a simple single loop and may use dual controllers, cascade control, or split gain blocks
- You want to converge parameters in simulation before moving to real hardware
- Your controller parameters are not named with the standard `P/I/D`, but use names such as `Kp/Ki/Kd` or `ProportionalGain/IntegralGain/DerivativeGain`
- You want the tool to adapt to an existing Simulink project instead of forcing you to rebuild the model structure

---

## How it works

```text
Simulink model  ──run one simulation round──>  output time series (To Workspace)
                                              │
                                  extract Time / Data arrays and compute
                                  error, overshoot, and steady-state error
                                              │
                                  LLM analyzes the current round + history
                                  and suggests new parameters
                                              │
                    write back one or more controller blocks
                    (or split P/I/D gain blocks)
                                              │
                                  continue to the next round ──> converge
```

Each round restarts the model from the initial state. The `SimTime(ms)` column is **simulation time in milliseconds**, not real-world time.

---

## Step 1: Install MATLAB Engine API for Python

This is a one-time setup. MATLAB R2021b and later include the package. Run the following inside your MATLAB installation:

```bash
cd <MATLAB_ROOT>/extern/engines/python
python setup.py install
```

Example Windows path:

```text
D:/Program Files/MATLAB/R2025b/extern/engines/python
```

Verify the install:

```bash
python -c "import matlab.engine; print('OK')"
```

---

## Step 2: Prepare your Simulink model

### One general trick: how to get any block path

`MATLAB_PID_BLOCK_PATH`, `MATLAB_PID_BLOCK_PATH_2`, `MATLAB_SETPOINT_BLOCK`, and `MATLAB_P/I/D_BLOCK_PATH(_2)` all expect a **full Simulink block path**.

Use the same workflow for every one of them:

1. Click the block you want in Simulink
2. In the MATLAB Command Window, run:

   ```matlab
   gcb
   ```

3. Copy the returned string directly into `config.json`

For example, if `gcb` returns:

```text
pid_tuner/Inner Loop/PID Controller
```

use that exact string as the block path.

If the block is inside a subsystem, the returned value already includes the hierarchy. You do not need to construct it manually.

### Required item 1: output signal

Connect the plant output you want to tune to a To Workspace block, then configure it like this:

1. Double-click the To Workspace block
2. Set **Variable name** to something like `y_out`
3. Set **Save format** to `Timeseries`
4. Set **Sample time** to `-1` (inherited) or the same step size as your model
5. Click OK

Manual verification:

```matlab
sim('your_model_name');
whos y_out
```

If your model uses inconsistent output variable names, you can later provide several candidates in `MATLAB_OUTPUT_SIGNAL_CANDIDATES`.

### Required item 2: controller parameters must be writable

The tool currently supports three common structures:

#### Option A: standard single controller block

This is the easiest and most reliable option. Typical examples:

- `PID Controller`
- `PI Controller`
- `PD Controller`
- `P Controller`

Supported parameter names include:

- `P` / `I` / `D`
- `Kp` / `Ki` / `Kd`
- `P_Gain` / `I_Gain` / `D_Gain`
- `ProportionalGain` / `IntegralGain` / `DerivativeGain`

#### Option B: dual controllers / cascade control

Typical examples:

- `Outer PID`
- `Inner PID`

The tool can write parameters to both controllers. Right now this support is best described as **minimum viable**, so explicit paths are recommended instead of relying entirely on auto-discovery.

#### Option C: split P/I/D gain blocks

If your controller is built from separate blocks instead of a single PID block, you can configure:

- one path for the P gain block
- one path for the I gain block
- one path for the D gain block

The tool will write compatible parameters such as `Gain`, `Value`, `K`, or `Coefficient`.

### Recommended: setpoint block

If the setpoint source is obvious in your model, record its block path and place it in `MATLAB_SETPOINT_BLOCK`.

This is usually more reliable than depending completely on auto-detection.

### Recommended: control output signal

If you can also send the controller output to To Workspace, for example `u_out`, put that variable name in `MATLAB_CONTROL_SIGNAL`.

That allows the tool to see the real controller output instead of a placeholder `PWM=0.0`, which gives the LLM better context.

---

## Step 3: Configure `config.json`

### Minimum single-controller configuration

```json
{
  "LLM_API_KEY": "your-key",
  "LLM_API_BASE_URL": "https://api.openai.com/v1",
  "LLM_MODEL_NAME": "gpt-4o",
  "LLM_PROVIDER": "openai",

  "MATLAB_MODEL_PATH": "C:/models/my_pid_model.slx",
  "MATLAB_PID_BLOCK_PATH": "my_pid_model/PID Controller",
  "MATLAB_ROOT": "D:/Program Files/MATLAB/R2025b",
  "MATLAB_OUTPUT_SIGNAL": "y_out",
  "MATLAB_SIM_STEP_TIME": 10.0,
  "MATLAB_SETPOINT": 200.0
}
```

### Field reference

| Field | Meaning | Example |
| :--- | :--- | :--- |
| `MATLAB_MODEL_PATH` | Full path to the Simulink `.slx` file | `C:/models/my_model.slx` |
| `MATLAB_PID_BLOCK_PATH` | Full path to the primary controller block | `my_model/PID Controller` |
| `MATLAB_ROOT` | MATLAB installation root directory | `D:/Program Files/MATLAB/R2025b` |
| `MATLAB_OUTPUT_SIGNAL` | To Workspace output variable name | `y_out` |
| `MATLAB_SIM_STEP_TIME` | Simulation time per tuning round, in simulation seconds | `10.0` |
| `MATLAB_SETPOINT` | Target setpoint value | `200.0` |

### Additional compatibility fields

| Field | When to use it | Meaning |
| :--- | :--- | :--- |
| `MATLAB_OUTPUT_SIGNAL_CANDIDATES` | Output variable names are inconsistent | Try several output names in order |
| `MATLAB_CONTROL_SIGNAL` | You want the LLM to see the real control output | For example `u_out`; if omitted, the bridge also tries common names like `u_out`, `u`, `pwm`, `control` |
| `MATLAB_SETPOINT_BLOCK` | Auto-detection of the setpoint source is unstable | Explicitly set the setpoint block |
| `MATLAB_PID_BLOCK_PATHS` | You have several likely controller paths | Provide a candidate path list |
| `MATLAB_PID_BLOCK_PATH_2` | Dual-controller / cascade model | Explicit path to the second controller |
| `MATLAB_P_BLOCK_PATH` `MATLAB_I_BLOCK_PATH` `MATLAB_D_BLOCK_PATH` | Controller uses split gain blocks instead of one PID block | Advanced compatibility mode for explicit split P/I/D gain block paths |
| `MATLAB_P_BLOCK_PATH_2` `MATLAB_I_BLOCK_PATH_2` `MATLAB_D_BLOCK_PATH_2` | Second split-gain controller | Advanced compatibility mode for dual-controller setups |

---

### How to choose these fields without getting confused

- Fields without a suffix belong to the first / primary controller; fields with `_2` belong to the second controller
- If you can edit the model, the most reliable setup is to tag the main PID block as `llm_pid_tuner_primary` and the secondary one as `llm_pid_tuner_secondary`
- If you already know the exact block path, prefer `MATLAB_PID_BLOCK_PATH`, `MATLAB_PID_BLOCK_PATH_2`, or `MATLAB_SETPOINT_BLOCK`
- If you are not sure which controller is the right one yet, but you can list a few candidates, use `MATLAB_PID_BLOCK_PATHS`
- Auto-discovery now prefers block Tags first, then standard `PID Controller` block types, and only then falls back to the older scoring heuristic
- `MATLAB_CONTROL_SIGNAL` and `MATLAB_SETPOINT_BLOCK` are recommended upgrades, not first-run requirements

---

## Recommended examples (grow from minimal to more capable)

### Example A: standard single PID Controller

This example starts from the minimum single-controller configuration and adds the recommended-but-optional `MATLAB_CONTROL_SIGNAL` and `MATLAB_SETPOINT_BLOCK`.

```json
{
  "MATLAB_MODEL_PATH": "C:/models/pid_tuner.slx",
  "MATLAB_PID_BLOCK_PATH": "pid_tuner/PID Controller",
  "MATLAB_ROOT": "D:/Program Files/MATLAB/R2025b",
  "MATLAB_OUTPUT_SIGNAL": "y_out",
  "MATLAB_CONTROL_SIGNAL": "u_out",
  "MATLAB_SETPOINT_BLOCK": "pid_tuner/Constant",
  "MATLAB_SIM_STEP_TIME": 15.0,
  "MATLAB_SETPOINT": 100.0
}
```

### Example B: dual controllers / cascade setup

```json
{
  "MATLAB_MODEL_PATH": "C:/models/cascade_pid.slx",
  "MATLAB_PID_BLOCK_PATH": "cascade_pid/Outer PID",
  "MATLAB_PID_BLOCK_PATH_2": "cascade_pid/Inner PID",
  "MATLAB_ROOT": "D:/Program Files/MATLAB/R2025b",
  "MATLAB_OUTPUT_SIGNAL": "y_out",
  "MATLAB_CONTROL_SIGNAL": "u_out",
  "MATLAB_SETPOINT_BLOCK": "cascade_pid/Setpoint",
  "MATLAB_SIM_STEP_TIME": 10.0,
  "MATLAB_SETPOINT": 100.0
}
```

### Example C: split P/I/D gain blocks

This is an advanced compatibility path. It still works, but it is no longer the recommended first-run configuration.

```json
{
  "MATLAB_MODEL_PATH": "C:/models/split_pid.slx",
  "MATLAB_P_BLOCK_PATH": "split_pid/P Gain",
  "MATLAB_I_BLOCK_PATH": "split_pid/I Gain",
  "MATLAB_D_BLOCK_PATH": "split_pid/D Gain",
  "MATLAB_ROOT": "D:/Program Files/MATLAB/R2025b",
  "MATLAB_OUTPUT_SIGNAL": "y_out",
  "MATLAB_CONTROL_SIGNAL": "u_out",
  "MATLAB_SETPOINT_BLOCK": "split_pid/Setpoint",
  "MATLAB_SIM_STEP_TIME": 10.0,
  "MATLAB_SETPOINT": 100.0
}
```

### Example D: start with candidate paths instead of one exact path

```json
{
  "MATLAB_MODEL_PATH": "C:/models/multi_loop.slx",
  "MATLAB_PID_BLOCK_PATHS": [
    "multi_loop/Outer PID",
    "multi_loop/Inner PID",
    "multi_loop/Backup Controller"
  ],
  "MATLAB_ROOT": "D:/Program Files/MATLAB/R2025b",
  "MATLAB_OUTPUT_SIGNAL": "y_out",
  "MATLAB_OUTPUT_SIGNAL_CANDIDATES": ["y_out", "yout", "plant_y"],
  "MATLAB_SIM_STEP_TIME": 10.0,
  "MATLAB_SETPOINT": 100.0
}
```

If Example D gets you running, the next recommended step is to replace the discovered primary controller with an explicit `MATLAB_PID_BLOCK_PATH`. That is usually more stable over time.

---

## What auto-discovery can do

The newer runtime prints a short discovery summary when the model starts, for example:

- primary controller path
- secondary controller path, if one is found
- setpoint block
- output signal
- control signal

This helps you:

1. confirm which controller block the runtime actually picked
2. separate "wrong path in config" problems from "model structure is not compatible" problems

> **Important:** auto-discovery is best-effort. For complex models, explicit primary controller, secondary controller, and setpoint paths are still the safest choice.

---

## Suggested rollout for complex configurations

If this is your first Simulink tuning setup, the safest path is:

1. Start with Example A and get a single controller working
2. Add `MATLAB_CONTROL_SIGNAL` so the LLM sees the real control output
3. If the model has multiple loops, add `MATLAB_PID_BLOCK_PATH_2`
4. Only switch to split `MATLAB_P/I/D_BLOCK_PATH` fields if your controller is not a standard PID block

Do not fill every advanced field on day one. The stable pattern is:

**start with the minimum workable config, then add compatibility fields one by one.**

---

## Step 4: Run

### Option A: via launcher (recommended)

```bash
llm-pid-tuner.exe
```

Choose "Simulink simulation tuning" from the menu. The tool will:
1. **Run environment diagnostics**: Automatically use `doctor.py` logic to check if MATLAB Engine is available and config fields are complete.
2. **Pre-Tuning Dialog** (interactive mode): Prompt you for natural language tuning preferences (e.g., "no overshoot allowed").
3. **Start tuning**: Launch MATLAB Engine, load the model, and begin tuning. 

When tuning finishes, press Enter to exit. The final parameters are saved back to the `.slx` file.

### Option B: call `simulator.py` directly

```bash
python simulator.py
```

When `MATLAB_MODEL_PATH` is set, `simulator.py` switches into Simulink mode automatically. No extra flags are required.
If you want to explicitly force the interface language (e.g., Chinese), use the `--lang` flag:
```bash
python simulator.py --lang zh
```

---

## Tuning strategy

The LLM still follows the same three-phase tuning sequence:

### Phase 1: tune P only

- Keep I near 0 and D = 0
- Increase P aggressively to find a useful gain region quickly

### Phase 2: add I to reduce steady-state error

- Only start increasing I after P is reasonably stable
- Increase I gradually until the steady-state error approaches zero
- If overshoot or oscillation appears, reduce I

### Phase 3: add D only if needed

- Only introduce D when the P+I combination still overshoots or oscillates noticeably
- Start with a small D
- If P+I already looks good, D can stay at 0

> **Note:** `SimTime(ms)` is simulation time in milliseconds, not real-world wall-clock time.

---

## Troubleshooting

### Q: `No module named matlab.engine`

The MATLAB Engine API is not installed yet. Follow Step 1, and make sure you run `setup.py install` inside the same Python environment used for this project.

### Q: `MATLAB connection failed` or startup timeout

- Verify that MATLAB is installed and licensed correctly
- Check `MATLAB_MODEL_PATH` for typos and prefer forward slashes `/` or escaped backslashes `\\`
- Check `MATLAB_ROOT` if you are using the packaged app or if source mode cannot find the runtime
- If you are using explicit block paths, re-select the block in Simulink and run `gcb` again to confirm the exact path
- The first MATLAB Engine startup can take 30 to 60 seconds, which is normal

### Q: To Workspace data is not found

- Confirm the To Workspace block uses **`Timeseries`**
- Confirm the variable name matches `MATLAB_OUTPUT_SIGNAL`
- If the output name is inconsistent, add `MATLAB_OUTPUT_SIGNAL_CANDIDATES`
- Run the model manually once in MATLAB and make sure the variable appears in the workspace

### Q: My model is not a single standard PID Controller. Can this still work?

Yes. In increasing order of complexity:

1. Standard controller block: fill `MATLAB_PID_BLOCK_PATH`
2. Dual-controller / multi-loop model: add `MATLAB_PID_BLOCK_PATH_2`
3. Split gain controller: use `MATLAB_P/I/D_BLOCK_PATH` and the `_2` variants when needed

If you are unsure which one applies, start with the explicit primary controller path and add complexity later.

### Q: Auto-discovery picked a strange block. What should I do?

Auto-discovery is only a fallback. For complex models:

- select the correct block in Simulink and run `gcb`
- fill `MATLAB_PID_BLOCK_PATH` explicitly
- fill `MATLAB_SETPOINT_BLOCK` explicitly
- if there is a second controller, also fill `MATLAB_PID_BLOCK_PATH_2`

That is the most stable setup.

### Q: Each round is slow

`MATLAB_SIM_STEP_TIME` controls how long each simulation round runs, in simulation seconds. Lowering it speeds up iteration, but each round still needs to be long enough to capture rise and settling behavior. A good starting point is roughly 3 to 5 times the system time constant.

### Q: When does Simulink tuning stop automatically?

Simulink plain mode and TUI mode use the same stopping logic. After an evaluation satisfies `GOOD_ENOUGH_AVG_ERROR`, `GOOD_ENOUGH_STEADY_STATE_ERROR`, and `GOOD_ENOUGH_OVERSHOOT`, the tool keeps the current PID values and observes the next rounds instead of asking the LLM for new parameters. It stops after `REQUIRED_STABLE_ROUNDS` consecutive stable evaluations, which defaults to 3; if the response gets worse during observation, the stable counter resets and normal tuning resumes.

### Q: Where are the tuned parameters saved?

When tuning finishes, or when you stop it manually, the current best parameters are written back into the `.slx` file. The next time you open the model in MATLAB, the controller blocks contain the tuned values.

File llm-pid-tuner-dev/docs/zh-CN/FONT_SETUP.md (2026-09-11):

# 字体配置

TUI 支持任何等宽字体，但安装 **JetBrains Mono Nerd Font** 后可显示完整图标集。
项目根目录的 `font/` 文件夹中已内置该字体文件。

## 方式一 — 安装内置字体

1. 打开项目根目录下的 `font/` 文件夹。
2. 右键 `JetBrainsMonoNerdFont-Regular.ttf` → **为所有用户安装**。

## 方式二 — 从官网下载

访问 https://www.nerdfonts.com/font-downloads，搜索 **JetBrainsMono**，
下载 zip 后解压，同样右键 `.ttf` 文件选择安装。

## 配置终端使用该字体

| 终端 | 操作路径 |
|---|---|
| **Windows Terminal** | 设置 → 配置文件 → 外观 → 字体 → 输入 `JetBrainsMono Nerd Font Mono` |
| **VS Code 内置终端** | 设置项 `terminal.integrated.fontFamily` 填写 `"JetBrainsMono Nerd Font Mono"` |
| **其他终端** | 在该终端自身的字体偏好设置中选择已安装的字体名称 |

修改字体后重启终端生效。

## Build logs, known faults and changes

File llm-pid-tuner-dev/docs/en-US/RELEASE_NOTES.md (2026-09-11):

# Release v2.1.0 PRO - Beginner-Friendly Hardware Tuning Build

Release date: 2026-03-06

This release is not about adding flashy features. It is about making the project **more reliable, easier to understand, and easier to use on real hardware**.

## What changed

### 1. New packaged `exe`

- The `llm-pid-tuner.exe` asset in this Release is updated to the latest build
- It targets the cleaned-up hardware tuning flow for Windows users

### 2. More stable tuning flow

- PID guardrails reduce the chance of runaway parameter jumps
- Fallback suggestions keep the loop moving when the LLM output is unusable
- The runtime remembers the best stable result seen so far
- It rolls back if a later suggestion clearly performs worse
- It stops early when the system is already “good enough”
- After meeting the `GOOD_ENOUGH_*` thresholds, the runtime keeps the current PID values for observation and stops after `REQUIRED_STABLE_ROUNDS` consecutive stable evaluations; the default is 3, and plain/TUI modes behave consistently

### 3. Better LLM endpoint compatibility

- Improved support for OpenAI-compatible APIs
- Direct HTTP fallback path when SDK behavior is not enough
- More robust JSON parsing for inconsistent model outputs

### 4. Docs rewritten for beginners

- `README.md` now leads with the packaged `exe` workflow
- clearer `config.json` guidance
- clearer serial / API / troubleshooting notes
- updated `docs/en-US/PROJECT_DOC.md` for maintainers and contributors

## Who should download this build

- Users who want to tune Arduino / ESP32 / other serial-connected hardware
- Windows users who do not want to install Python first
- People who want to start using the tool before reading the source code

## Recommended usage

1. Download `llm-pid-tuner.exe` from this Release
2. Prepare your board, ideally starting from `firmware.cpp`
3. Run the exe once to generate `config.json`
4. Fill in your API and serial settings
5. Run the exe again and start tuning

## Config example

```json
{
  "SERIAL_PORT": "AUTO",
  "BAUD_RATE": 115200,
  "LLM_API_KEY": "sk-your-key",
  "LLM_API_BASE_URL": "https://api.openai.com/v1",
  "LLM_MODEL_NAME": "gpt-4",
  "LLM_PROVIDER": "openai"
}
```

For MiniMax, DeepSeek, Ollama, or LM Studio style OpenAI-compatible endpoints, you usually only need to change:

- `LLM_API_BASE_URL`
- `LLM_MODEL_NAME`
- `LLM_API_KEY`

and keep:

```json
{
  "LLM_PROVIDER": "openai"
}
```

## Upgrade notes

- If you downloaded the older Release from four days ago, download the new `llm-pid-tuner.exe`
- If you already have an older `config.json`, compare it with the updated `README.md`
- If you run from source, also review `docs/en-US/README.md` and `docs/en-US/PROJECT_DOC.md`

## Safety reminder

This project is built to help you reach usable PID parameters faster. It does **not** replace hardware safety protections.

For real hardware, still keep:

- over-temperature protection
- sensor fault handling
- power-stage fault protection
- human supervision

---

After downloading, start with `docs/en-US/README.md:1` or `docs/en-US/README.md:1` depending on your language preference.

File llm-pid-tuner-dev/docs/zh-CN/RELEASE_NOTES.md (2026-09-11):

# Release v2.1.0 PRO - 新手可直接上手的硬件调参版

发布日期：2026-03-06

这个版本的重点不是堆功能，而是把项目整理成一个**更稳、更好懂、更适合真实调参**的形态。

## 这次更新了什么

### 1. 发布了新的 `exe`

- Release 资产里的 `llm-pid-tuner.exe` 已更新到最新构建
- 对应的是整理后的主流程版本，更适合直接给 Windows 用户使用

### 2. 调参流程更稳

- 加入了 PID 护栏，避免参数一口气跑飞
- LLM 给不出可用结果时，会使用保底建议继续工作
- 会记录历史最佳稳定结果
- 如果后续某轮建议让效果明显变差，会自动回退到更好的历史参数
- 当系统已经“够好”时，会尽量提前停止，避免越调越坏
- 达到 `GOOD_ENOUGH_*` 阈值后会先保持当前 PID 观察，连续 `REQUIRED_STABLE_ROUNDS` 轮稳定后停止；默认稳定轮数为 3，plain 和 TUI 模式行为一致

### 3. LLM 接口兼容性更好

- 对 OpenAI 兼容接口更友好
- SDK 路径不顺时，会尝试更直接的 HTTP 路径
- 对返回 JSON 的解析更稳，减少格式抖动导致的失败

### 4. 文档重写为“小白优先”

- `README.md` 现在把 `exe` 用法放在最前面
- 明确说明 `config.json` 怎么填
- 加入更清晰的串口、API、常见报错排查说明
- 补充 `docs/zh-CN/PROJECT_DOC.md` 方便后续维护和二次开发

## 最适合谁下载这个版本

- 想直接调 Arduino / ESP32 / 其他串口控制板
- 不想先安装 Python 环境
- 想先用起来，再决定要不要看源码

## 打包版的推荐使用方式

1. 从本 Release 下载 `llm-pid-tuner.exe`
2. 准备好你的硬件，并尽量从 `firmware.cpp` 开始适配
3. 首次运行 exe，让程序生成 `config.json`
4. 填好 API 配置和串口配置
5. 再运行 exe，开始调参

## 配置示例

```json
{
  "SERIAL_PORT": "AUTO",
  "BAUD_RATE": 115200,
  "LLM_API_KEY": "sk-your-key",
  "LLM_API_BASE_URL": "https://api.openai.com/v1",
  "LLM_MODEL_NAME": "gpt-4",
  "LLM_PROVIDER": "openai"
}
```

如果你使用 MiniMax / DeepSeek / Ollama / LM Studio 这类 OpenAI 兼容接口，通常只需要改：

- `LLM_API_BASE_URL`
- `LLM_MODEL_NAME`
- `LLM_API_KEY`

并保持：

```json
{
  "LLM_PROVIDER": "openai"
}
```

## 升级说明

- 如果你之前下载过四天前的旧 Release，请重新下载本次新的 `llm-pid-tuner.exe`
- 如果你之前已经有旧的 `config.json`，建议对照新的 `README.md` 检查字段是否完整
- 如果你是源码用户，建议同步更新 `README.md`、和 `docs/zh-CN/PROJECT_DOC.md`

## 仍然要提醒的事

这个项目的目标是**帮你更轻松地找到可用 PID 参数**，不是替代硬件安全保护。

真实硬件调参时，请务必做好：

- 超温保护
- 传感器异常保护
- 功率级失控保护
- 人工值守

---

下载后建议先看 `README.md:1`，按“3 分钟上手：Windows 打包版”那一节直接开始。

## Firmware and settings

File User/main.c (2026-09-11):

#include "stm32f4xx.h"
#include "./led/bsp_led.h"
#include "Delay.h"
#include "OLED.h"
#include "Timer.h"
#include "pwm.h"
#include "pid.h"
#include "line_follow.h"
#include "enconder.h"
#include "motor.h"
#include "line_sensor.h"
#include "smooth_servo.h"
#include "arm_config.h"
#include "command.h"
#include "servo.h"
#include "hc_sr40.h"
#include "uart.h"
#include "action_group.h"
#include "state_machine.h"
#include "commend_openmv.h"
#include "visual_servo.h"
#include <stdio.h>
#include <string.h>

uint8_t KEYNUM;
uint16_t NUM;

#define MODE_MANUAL       0
#define MODE_LINE_FOLLOW  1
#define MODE_POSITION     2
/* MODE_VISUAL_SERVO 3 is defined in visual_servo.h */

/* ======  ======
   1 = ,  MANUAL , AI
       /
   0 =  (+AI) */
#define TEST_MODE 0
#define SKIP_DOCK 1   /* 调试开关: 1=上电跳过对接(直接进回轨 dock_state7 + Station0/1), 0=正常对接流程 */

volatile uint8_t work_mode = MODE_MANUAL;
volatile uint8_t motor_enable = 0;
uint8_t g_delivery_mode = 0;  /* delivery: 1= */
Line_follow_Handle line_follow;
PID_Handle pid_positon[4];
int32_t target_position[4] = {0,0,0,0};
PID_Handle pid_motor[4];
volatile int16_t target_speed[4] = {0, 0, 0, 0};
int8_t motor_dir[4] = {1, -1, 1, -1};
int8_t encoder_dir[4] = {-1, -1, -1, -1};
int16_t encoder_max[4] = {2500, 2500, 2500, 0};
VisualServo_Handle visual_servo;
TaskQueue task_queue;
volatile uint8_t trailer_docked = 0;   /* 从车已挂接: 1=完成 */
extern volatile uint8_t trailer_dock_flag;  /* ISR 十字路口触发 */
volatile uint8_t dock_test_flag = 0;   /* dock_test: 1=车已对准, 直接进倒车对接 */
volatile uint8_t dock_tune_flag = 0;   /* dock_tune: 1=自动循环对接调参 (不挂钩) */
volatile uint8_t dock_tune_on   = 0;   /* 调参循环模式: 到达38cm后前进离开再倒车 */
volatile uint8_t telem_enable   = 0;   /* telem: 1=遥测流开启(tuner用), 默认关防刷屏 */
volatile uint8_t lf_dbg_enable  = 0;   /* lfdbg: 1=巡线调试打印(传感器/速度/PID输出) */
extern int16_t last_pid_setpoint[4];   /* Timer.c 速度环记录 */
extern int16_t last_pid_speed[4];
extern int16_t last_pid_output[4];
/* 对接状态机全局 (dockstat 调试命令可读) */
volatile uint8_t  dock_state = 0;      /* 0=idle 1=右拐 2=找码 3=倒车 4=挂钩 5=完成 6=调参离开 */
volatile uint32_t dock_tick = 0;
volatile uint8_t  dock_lost = 0;
volatile uint8_t  dock_offline_cnt = 0;
volatile uint8_t  dock_tune_once = 0;  /* dock_tune 初始化一次性标志 (退出时复位) */
volatile uint8_t  cross_dock_enable = 0; /* crossdock: 1=启用十字路口自动对接 (boot 开跑置1, crossdock 0/1 切换) */
volatile uint8_t  dock_done_once = 0;    /* dock_state==5 一次性标志 (run/restart 复位后可重新开跑) */
volatile uint8_t  trace_enable = 0;      /* trace: 1=周期性打印dock/电机状态(定位用) */
/* 十字路口原地右转90° (dock_state 1): 停车→原地差速右转90°→停→转腰座对接.
   停止: 先"深离开"(在线≤2)再"≥4路在线"(对齐竖线); 1.5s最小旋转防误判; 4s兜底; 8s安全超时 */
#define DOCK_PIVOT_SPD     195    /* 原地右转开环速度(左+195/右-195, 用户要求: 200→195) */
#define DOCK_PIVOT_MIN     150    /* 最小旋转时间 1.5s 后才允许判90° (防起步传感器抖动误停) */
#define DOCK_PIVOT_CAP     330    /* 时间兜底 3.3s (用户要求: 3.5s减0.2s) */
#define DOCK_PIVOT_TO      800    /* 安全超时 8s (CAP 之后基本不会到) */
static uint8_t  dock_pv_phase = 0;    /* dock_state1: 0=停车 1=旋转 */
static uint8_t  dock_pv_dropped = 0;  /* 旋转中已"深离开"0° (在线≤2路) */
volatile int16_t  dock_last_cx = -1;     /* 最后有效码 cx (trace 显示, 不受 GetData 消费影响) */
volatile int16_t  dock_last_dist = -1;   /* 最后有效码 dist */
#define DOCK_WAIST_ALIGN_DIR   1         /* 腰座对准方向: trace 实证 waist↑→cx↑(码更右), 码偏右应减小waist → +1 */
#define DOCK_RR_PCT            7         /* 右后轮开环补偿(比例式): 右后轮无编码器开环, 按 |target_speed[3]| 的 7% 反向补偿
                                           (倒车时右后轮稍快, 减速 7% 与左轮一致); 全速度段比例恒定.
                                           若车仍向右偏就减小, 向左偏就加大 */
#define DOCK_INNER_OPENLOOP    1         /* 倒车内环开环开关(2026-08-24): 1=视觉伺服主回路保留, 只跳过编码器速度内环
                                           (编码器方向乱/接触不良时速度环正反馈→车原地转不后退); 0=恢复速度闭环 */
#define DOCK_RF_PCT            15        /* 右前轮(电机1)倒车补偿(比例式): 右前轮低速时实际出力偏小
                                           (日志 spd=-51 右前/右后明显低于左轮 -76, 电机死区附近跑不动),
                                           倒车时按 |target_speed[1]| 的 15% 加大右前轮速度(更负=更有力).
                                           只补偿倒车段(负速度), 不影响正向前进 */
volatile uint8_t qr_trig_flag = 0;   /* : QR */
/* AI 流水线站/目标序号 (全局化: SKIP_DOCK 启动可预设起始站, 原为主循环块内 static) */
uint8_t station_idx = 0;    /* 0=Station0(抓取放从车) 1=Station1(交付) */
uint8_t mission_idx = 0;    /* 当前目标序号 0..MISSION_COUNT-1 */
volatile uint8_t ai_dbg_stat = 0;    /* ai_stat: dump AI pipeline state */
volatile uint8_t ai_dbg_skip = 0;    /* ai_skip: skip current target */
volatile uint8_t ai_dbg_go   = 0;    /* ai_go: jump to phase */
volatile uint8_t ai_dbg_phase = 0;   /* ai_go target phase */
volatile uint8_t ai_restart_flag = 0; /* restart: reset AI pipeline */
volatile uint8_t flow_dbg = 0;        /* flow: dump whole run-flow state (main loop handler) */
volatile uint8_t flow_stage = 1;      /* LED 阶段指示: 1=巡线 2=对接 3=工位 4=全部完成 (无串口也可见) */
static  uint8_t dock_st2_init = 0;    /* dock_state==2 一次性初始化标志 (全局, 便于复位) */
static  uint32_t dock_st2_start = 0;  /* dock_state==2 进入时刻 (30s 总超时用) */
static  uint8_t dock_st7_init = 0;    /* dock_state==7(回轨) 一次性初始化 */
static  uint8_t dock_st7_phase = 0;   /* dock_state==7: 0=脱线直行 1=原地左转 */

// LEDn
static void LedBlink(int n)
{
    int j;
    for (j = 0; j < n; j++) {
        GPIO_ResetBits(GPIOF, GPIO_Pin_9);  // LED ON
        Delay_ms(200);
        GPIO_SetBits(GPIOF, GPIO_Pin_9);    // LED OFF
        Delay_ms(200);
    }
}

// 
static void MotorSelfTest(void)
{
    int j;
    for (j = 0; j < 4; j++) {
        Motor_SetSpeed(j, 400);
        Delay_ms(300);
        Motor_SetSpeed(j, 0);
        Delay_ms(200);
        Motor_SetSpeed(j, -400);
        Delay_ms(300);
        Motor_SetSpeed(j, 0);
        Delay_ms(200);
    }
}

int main(void)
{
    int i;
    char cmd[64];

    SystemInit();
    SysTick_Init();  // 1ms SysTick
    NVIC_PriorityGroupConfig(NVIC_PriorityGroup_2);
    DBGMCU->CR &= ~(DBGMCU_CR_TRACE_IOEN | (0x3 << 6));

    Motor_EmergencyBrake();

    LED_Init();
    GPIO_SetBits(GPIOF, GPIO_Pin_9);  // LED off initially

    uart_Init();
    printf("a\r\n");        //  a
    /* OLEDI2C */
    /* OLED_Init(); */
    /* OLED_Clear(); */
    /* OLED_ShowString(0,0,(u8*)"Init...",16,1); */
    /* BT_Init(); -- , USART2, UART5(PC12/PD2) */
    OpenMV_Init();

    Motor_Init();
    PWM_init();
    Delay_ms(200);          // PWM[
    Servo_Init();
    smooth_Init();
    ArmSM_Init();
    Action_ParamInit();

    Encoder_Init();
    Line_sensor_Init();

    /* 视觉伺服: tag_id=1=从车AprilTag, 目标40cm(触发到位), 基准160 (负重太慢再加力).
       横向 P-only kp=1.0 + 死区±3px: 轮子差速转向要有劲 (kp=0.8 时转向偏软,
       用户反馈"差速旋转太小"); 腰座在 dist>45cm 时负责粗对准,
       45cm 内交给轮子差速, 防腰座棘轮顶限位.
       纵向 P-only kp=1.5. I/D 全 0: 主循环只在 30fps 新帧时调用 (dt 实为 33ms 非 0.01),
       微分项被放大 3.3 倍会加剧甩头, 积分在横向上会越积越偏 */
    VisualServo_Init(&visual_servo, 1, 40,
        160, 1.0f, 0.0f, 0.0f, 1.5f, 0.0f, 0.0f, 0.01f);
    TaskQueue_Init(&task_queue);

    lineFollow_Init(&line_follow, 180, 180.0, 2.0, 2.0, 0.01);
    PID_Init(&pid_motor[0], PID_INCREMENTAL, 5.5, 0.16, 0.0, 300, 1000, 300);  // 
    PID_Init(&pid_motor[1], PID_INCREMENTAL, 5.5, 0.16, 0.0, 300, 1000, 300);  // 
    PID_Init(&pid_motor[2], PID_INCREMENTAL, 5.0, 0.14, 0.0, 300, 1000, 300);  // 
    PID_Init(&pid_motor[3], PID_INCREMENTAL, 5.0, 0.14, 0.0, 300, 1000, 300);  //  
    for(i=0; i<4; i++)
        PID_Init(&pid_positon[i], PID_POSITION, 0.5, 0.001, 0, 200, 600, 300);

    Timer_Init();
    PVD_Init();         // VDD<2.9V

    // PID
    for (i = 0; i < 4; i++) {
        Motor_SetSpeed(i, 0);
        PID_Reset(&pid_motor[i]);
        PID_Reset(&pid_positon[i]);
    }

    motor_enable = 0;
    target_speed[0] = 0;
    target_speed[1] = 0;
    target_speed[2] = 0;
    target_speed[3] = 0;

#if !TEST_MODE
    // ======  ======
    work_mode = MODE_LINE_FOLLOW;
    motor_enable = 1;
    Action_Reset();
    while (!Action_ISdle());

    // ======  ======
    OpenMV_SendCmd("MODE,QRCODE");  /* QR */

    /* ====== 开跑: 整流程自动启动 ======
       line-follow -> 十字路口(5路全踩) -> 右拐 -> 脱线对准
       -> AprilTag 倒车对接 -> 挂钩 -> Station0(抓3件放从车)
       -> Station1(从车取件交付) -> 完成 LED 三闪 */
    cross_dock_enable = 1;   /* 十字路口自动对接默认开启, crossdock 0/1 可关 */
    flow_stage = 1;          /* LED 慢闪 = 巡线阶段 */
#if SKIP_DOCK
    /* 调试: 上电默认已勾住从车 — 钩子保持勾住(10°夹紧)状态, 不转腰座/不重挂, 直接巡线进 Station0/1.
       (车需手动挂好从车; 上电只把钩子舵机保持勾住角度, 腰座朝前) */
    cross_dock_enable = 0;
    smooth_Settarget(SERVO_HOOK, ARM_HOME_HOOK, 500);   /* 钩子保持勾住(夹紧) */
    OpenMV_SendCmd("MODE,QRCODE");   /* 确保 OpenMV 在 QRCODE 模式, Station0 靠 QR 触发 */
    trailer_docked = 1;        /* 默认已勾住从车 */
    dock_done_once = 1;        /* 对接完成: dock_state5 不再转腰座/进回轨 */
    dock_state = 5;            /* 完成态: AI 流水线激活 → Station0/1 */
    encoder_max[1] = 0;        /* 右前开环(编码器real乱跳→PID猛反→乱转, lfdbg证实) */
    encoder_max[2] = 0;        /* 左后开环(编码器接触不良 real反向→PID输出反→左后倒着跑) */
    work_mode = MODE_LINE_FOLLOW;
    motor_enable = 1;
    target_speed[0] = 180; target_speed[1] = 180;
    target_speed[2] = 180; target_speed[3] = 170;

    /* ===== START_AT_STATION1: 上电直接进 Station1(交付), 跳过 Station0 抓取与巡线 =====
       0=上电巡线跑全流程(Station0->Station1); 1=原地等待5s自动触发Station1.
       车需摆放在 Station1 二维码正前方 15~40cm 对准; 上电原地等待,
       5s 后 (qr_phase=0 内 g_sys_tick>=500) 自动触发 approach -> 170°定位取件 -> 交付,
       全程无需任何串口命令。跑完 3 件(红黄绿)自动 mission_done 停车。 */
    #define START_AT_STATION1  0
    #if START_AT_STATION1
        station_idx   = 1;              /* 从交付站开始 */
        mission_idx   = 0;              /* 第一件: 红(class0) */
        work_mode     = MODE_MANUAL;    /* 不巡线: 原地等待自动触发 */
        target_speed[0] = 0; target_speed[1] = 0;
        target_speed[2] = 0; target_speed[3] = 0;
        qr_trig_flag  = 1;              /* 上电自动触发 Station1 */
        printf("START_AT_STATION1: station=%d mission=%d, 5s auto-trigger\r\n",
               (int)station_idx, (int)mission_idx);
    #endif

    printf("===== AGV RUN FLOW READY (SKIP DOCK, HOOKED) =====\r\n");
    printf("flow: line-follow -> Station0 -> Station1\r\n");
#else
    printf("===== AGV RUN FLOW READY =====\r\n");
    printf("flow: line-follow -> crossroad dock -> Station0 -> Station1\r\n");
    printf("cross_dock_enable=1 (crossroad auto-dock ON)\r\n");
#endif
#else
    // ====== : ,  ======
    work_mode = MODE_MANUAL;
    motor_enable = 0;
    printf("TEST MODE: manual control only\r\n");
    Action_Reset();
    while (!Action_ISdle());
    smooth_Settarget(0, ARM_HOME_WAIST,   800);
    smooth_Settarget(1, ARM_HOME_SHOULDER, 800);
    smooth_Settarget(2, ARM_HOME_ELBOW,    800);
    printf("Arm reset done, ready for manual commands.\r\n");
#endif
    LedBlink(3);        // LED3 = MCU

    //  USB-TTL ISR 
    while (uart_rb_getchar() >= 0);

    // 
    {
        uint32_t loop_start_tick;
        loop_start_tick = g_sys_tick;

    while (1)
    {
        /* ++ */
        {
            static uint8_t  line_idx = 0;
            static char     line_buf[64];
            int ch_int;
            uint8_t ch;
            uint32_t uptime;

            uptime = g_sys_tick - loop_start_tick;

            /* (ISRprintfE) */
            while ((ch_int = uart_rb_getchar()) >= 0)
            {
                ch = (uint8_t)ch_int;
                /* 3,  */
                if (uptime < 300)
                {
                    if (ch == '\r' || ch == '\n')
                    {
                        if (line_idx > 0)
                        {
                            line_buf[line_idx] = '\0';
                            line_idx = 0;
                            uart_set_bt_output(0);
                            Commend_Parse(line_buf);
                        }
                    }
                    else if (line_idx < (sizeof(line_buf) - 1))
                    {
                        line_buf[line_idx++] = ch;
                    }
                    continue;
                }
                /* ++, $TAGOpenMV */
                if ((ch >= 'a' && ch <= 'z') ||
                    (ch >= 'A' && ch <= 'Z') ||
                    (ch >= '0' && ch <= '9') ||
                    ch == ' ' || ch == '_' || ch == '-' ||
                    ch == '.' || ch == ':' || ch == '=' ||
                    ch == '\r' || ch == '\n')
                    uart_sendbyte(ch);
                if (ch == '\r' || ch == '\n')
                {
                    if (line_idx > 0)
                    {
                        line_buf[line_idx] = '\0';
                        line_idx = 0;
                        uart_set_bt_output(0);
                        Commend_Parse(line_buf);
                    }
                }
                else if (line_idx < (sizeof(line_buf) - 1))
                {
                    line_buf[line_idx++] = ch;
                }
            }

            /* RX  ISR  , 
             * ( RXNE  ISR ) */
        }

        // ======  (,  QR ) ======
#if 0
        {
            static uint8_t  auto_phase = 0;  /* 0=, 1=, 2= */
            static uint32_t phase1_start_tick = 0;  /*  */
            switch (auto_phase) {
                case 0:  /* : 5s   */
                    if (g_sys_tick >= 500) {
                        motor_enable = 0;
                        work_mode = MODE_MANUAL;
                        for (i = 0; i < 4; i++) {
                            target_speed[i] = 0;
                            PID_Reset(&pid_motor[i]);
                            Motor_SetSpeed(i, 0);
                        }
                        Delay_ms(300);
                        Action_Grasp();
                        phase1_start_tick = g_sys_tick;
                        auto_phase = 1;
                        work_mode = MODE_LINE_FOLLOW;
                        motor_enable = 1;
                    }
                    break;
                case 1:  /* 17s   */
                    if (g_sys_tick - phase1_start_tick >= 1700) {
                        motor_enable = 0;
                        work_mode = MODE_MANUAL;
                        for (i = 0; i < 4; i++) {
                            target_speed[i] = 0;
                            PID_Reset(&pid_motor[i]);
                            Motor_SetSpeed(i, 0);
                        }
                        Delay_ms(300);
                        Action_Place(act_angle[ACT_PLACE_WAIST]);
                        auto_phase = 2;
                        work_mode = MODE_LINE_FOLLOW;
                        motor_enable = 1;
                    }
                    break;
                default:  /* ,  */
                    break;
            }
        }
#endif

        /*  OpenMV ,  AI  */
        OpenMV_PollLine();

        // ====== AI : AI ======
        // : QR, AI ()
#if !TEST_MODE

        #define STATION_MODE      1   /* 1=() 0= */
        /*    */
        #define GRASP_TARGET_CM    6    /*  (cm) */
        #define PLACE_TARGET_CM    6    /*  (cm) */
        #define ALIGN_DIST_DEAD    2    /*  (cm) */
        /* -:  cx 
           160=, (180), (140) */
        #define GRASP_CX_TARGET   190   /* ,  */
        #define TRAILER_PLACE_CX  210   /* cx:  */
        #define MISSION_COUNT      3   /*  */

        {
            /* ---- : (0)(2)(1) ---- */
            static int8_t  mission_class[MISSION_COUNT] = {0, 2, 1};
            /* (1= 2= 3=), =color-1 */
            static int16_t color_cx[3]        = {210, 170, 190};  /*   :  */
            static int16_t color_grasp_dist[3] = {  6,   6,   6};  /*   : 6cm, cxdist */
            static int16_t color_conf_min[3]  = { 30,  30,  50};  /* AI conf 阈值: 红45→35→30(仍不稳), 绿30, 黄50 */
            static int16_t color_scan_deg[3] = {  5,   5,   5};  /* O: 5 */
            /* 识别色卡时腰座写死角度: [color_id] = 角度 (1红=90, 2绿=100, 3黄=80) */
            static int16_t identify_waist[4]  = {  0,  90, 100,  80 };
            /* 交付(放置)腰座写死角度: [color_id] = 角度 — 三个放不同位置
               (1红=90中间, 2绿=110, 3黄=70) */
            static int16_t deliver_waist[4]   = {  0,  90, 110,  70 };
            static uint8_t mission_done = 0;
            /* station_idx / mission_idx 已全局化(文件顶部), 启动可预设起始站 */
            static uint8_t total_stations = 2;  /* : 0=, 1= */
            static uint32_t mission_last_print = 0;
            static uint8_t  qr_phase = 0;      /* 0= 1=AI 2= 3= */
            static uint32_t qr_phase_tick = 0;
            static uint32_t qr_cooldown_end = 0; /* ,  */
            static uint8_t  qr_is_place = 0;   /* 0= 1=  STATION_MODEPhase7/9,  */
            static uint8_t  qr_target_color = 1; /* AI */
            static uint8_t  qr_aligned_cnt = 0;  /*  */
            static uint8_t  qa_window = 0;       /* QuickAlign: bit0=, 5 */
            static float    qa_anchor = 90.0f;   /* QuickAlign 锚点: 进入时角度, 限幅±30防失控转远 */
            static uint8_t  qr_scan_started = 0; /* 0= 1= */
            static float    qr_waist_center = 90.0f; /* AI,  (270) */
            /* Bug#1: Phase 2  () */
            static uint8_t  qr_phase2_arm_done = 0; /* Phase2.0  */
            /* 识别确认计数: 累计可见 tick, 防识别瞬间跳过直接转170° */
            static uint16_t id_hit_cnt = 0;
            /* Bug#2: ,  */
            static uint16_t nodata_start = 0;
            static uint8_t  scan_step   = 0;
            static uint16_t scan_tick   = 0;
            static uint16_t dbg_tick    = 0;  /* printf  */
            /* Bug#4: Phase 1  */
            static uint8_t  phase1_scan_step = 0;
            static uint16_t phase1_scan_tick = 0;
            /* Phase 9 skip-pick: 1Phase6Phase9 */
            static uint8_t  qr_skip_pick = 0;
            /* Phase 4 m */
            static uint32_t qr_place_phase_start = 0;
            OpenMV_CLSData  cls;
            OpenMV_Data     omv;
            int j;

            /* ====== AI debug commands (set by command.c) ====== */
            if (ai_dbg_stat) {
                ai_dbg_stat = 0;
                printf("[AI] phase=%d mission=%d/%d station=%d/%d"
                       " class=%d is_place=%d\r\n",
                       (int)qr_phase, (int)mission_idx, MISSION_COUNT,
                       (int)station_idx, total_stations,
                       (int)mission_class[mission_idx],
                       (int)qr_is_place);
                printf("[AI] scan: deg=%d waist=%.0f started=%d"
                       " step=%d tick=%d\r\n",
                       (int)color_scan_deg[mission_class[mission_idx]],
                       (double)qr_waist_center, (int)qr_scan_started,
                       (int)phase1_scan_step, (int)phase1_scan_tick);
                printf("[AI] align: phase=%d cnt=%d tgt_cx=%d"
                       " tgt_dist=%d conf_min=%d\r\n",
                       (int)qr_aligned_cnt,
                       (int)color_cx[qr_target_color - 1],
                       (int)color_grasp_dist[qr_target_color - 1],
                       (int)color_conf_min[mission_class[mission_idx]]);
            }
            /* ====== flow: 全流程状态一屏 dump (dock + AI + 电机) ====== */
            if (flow_dbg) {
                flow_dbg = 0;
                printf("[FLOW] wm=%d en=%d cross=%d dock_st=%d"
                       " lost=%d tune=%d docked=%d\r\n",
                       (int)work_mode, (int)motor_enable,
                       (int)cross_dock_enable, (int)dock_state,
                       (int)dock_lost,
                       (int)dock_tune_on, (int)trailer_docked);
                printf("[FLOW] phase=%d m=%d/%d st=%d/%d done=%d"
                       " place=%d color=%d dlv=%d\r\n",
                       (int)qr_phase, (int)mission_idx, MISSION_COUNT,
                       (int)station_idx, total_stations,
                       (int)mission_done, (int)qr_is_place,
                       (int)qr_target_color, (int)g_delivery_mode);
                printf("[FLOW] spd=%d,%d,%d,%d waist=%.0f cls=[%d,%d,%d]\r\n",
                       (int)target_speed[0], (int)target_speed[1],
                       (int)target_speed[2], (int)target_speed[3],
                       (double)smooth_GetCurrentAngle(0),
                       (int)mission_class[0], (int)mission_class[1],
                       (int)mission_class[2]);
            }
            if (ai_dbg_skip) {
                ai_dbg_skip = 0;
                printf("[AI] skip: advancing mission_idx %d->%d\r\n",
                       (int)mission_idx, (int)(mission_idx + 1));
                mission_idx++;
                if (mission_idx >= MISSION_COUNT) {
                    printf("[AI] skip: all objects done,"
                           " next station\r\n");
                    mission_idx = 0;
                    station_idx++;
                    if (station_idx >= total_stations) {
                        mission_done = 1;
                        flow_stage = 4;     /* LED 常亮 = 全部完成 */
                        printf("[AI] ALL STATIONS DONE\r\n");
                    }
                }
                OpenMV_SendCmd("MODE,QRCODE");
                LineFollow_Reset(&line_follow);
                work_mode = MODE_LINE_FOLLOW;
                motor_enable = 1;
                target_speed[0] = 180; target_speed[1] = 180;
                target_speed[2] = 180; target_speed[3] = 170;
                qr_cooldown_end = g_sys_tick + 500;
                qr_phase = 0;
                qr_scan_started = 0;
                nodata_start = 0;
                scan_step    = 0;
                scan_tick    = 0;
                dbg_tick     = 0;
                phase1_scan_step = 0;
                phase1_scan_tick = 0;
                id_hit_cnt = 0;
                qr_is_place = 0;
            }
            if (ai_dbg_go) {
                uint8_t target = ai_dbg_phase;
                ai_dbg_go = 0;
                printf("[AI] go: phase %d -> %d\r\n",
                       (int)qr_phase, (int)target);
                qr_phase = target;
                qr_phase_tick = g_sys_tick;
                qr_scan_started = 0;
                nodata_start = 0;
                scan_step    = 0;
                scan_tick    = 0;
                dbg_tick     = 0;
                phase1_scan_step = 0;
                phase1_scan_tick = 0;
                id_hit_cnt = 0;
            }
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

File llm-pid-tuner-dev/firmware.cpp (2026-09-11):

/**
 * ============================================================================
 * firmware.cpp - 基于 LLM 的 PID 自动调参系统 - MCU 端固件
 * ============================================================================
 *
 * 作者: KINGSTON-115
 * 功能：内置仿真模型 + 数据上报 + 指令接收
 * 目标平台：Arduino / PlatformIO
 *
 * 【数据流说明】
 * MCU (下位机) -> Serial TX -> Python (上位机) -> LLM (决策大脑)
 *                                           |
 *                                           v
 *                                    LLM 返回新参数
 *                                           |
 *                                           v
 *    Python   -> Serial RX -> MCU (更新 PID 参数)
 *
 * ============================================================================
 */

#include <Arduino.h>

// ---------------------------------------------------------------------------
// 全局配置
// ---------------------------------------------------------------------------
#define SERIAL_BAUD 115200      // 串口波特率
#define CONTROL_INTERVAL_MS 50  // 控制周期 (50ms)

// ---------------------------------------------------------------------------
// PID 参数 (全局变量，会被上位机更新)
// ---------------------------------------------------------------------------
float kp = 1.0f;   // 比例系数
float ki = 0.1f;   // 积分系数
float kd = 0.05f; // 微分系数

// ---------------------------------------------------------------------------
// 仿真模型参数 (虚拟被控对象：带惯性的加热系统)
// ---------------------------------------------------------------------------
float setpoint     = 100.0f;  // 目标温度
float current_temp = 20.0f;   // 当前温度 (初始环境温度)
float pwm_output   = 0.0f;    // PWM 输出

// ---------------------------------------------------------------------------
// PWM 安全限制 (电机保护)
// ---------------------------------------------------------------------------
const float PWM_MAX        = 6000.0f;  // PWM 上限 (满转10000)
const float PWM_CHANGE_MAX = 500.0f;   // 每周期最大 PWM 变化量
float prev_pwm_output      = 0.0f;     // 上一次 PWM 输出
float prev_error           = 0.0f;     // 上一次误差 (用于微分计算)
float integral             = 0.0f;     // 积分项

// ---------------------------------------------------------------------------
// 时间管理
// ---------------------------------------------------------------------------
unsigned long last_control_time = 0;
unsigned long timestamp_ms      = 0;

// ---------------------------------------------------------------------------
// 函数声明
// ---------------------------------------------------------------------------
void updateSimulation();       // 更新仿真模型
void computePID();            // 计算 PID 输出
void processSerialCommand();   // 处理上位机指令
void sendDataToSerial();       // 上报数据给上位机

// ---------------------------------------------------------------------------
// 初始化
// ---------------------------------------------------------------------------
void setup() {
    Serial.begin(SERIAL_BAUD);
    while (!Serial) {
        ; // 等待串口就绪
    }

    // 初始化仿真模型
    current_temp = 20.0f;
    pwm_output   = 0.0f;
    integral     = 0.0f;
    prev_error   = 0.0f;
    timestamp_ms = 0;

    // 打印初始化信息
    Serial.println("# LLM PID Tuner Firmware v1.0 Ready");
    Serial.println("# Format: timestamp_ms,setpoint,input,pwm,error,p,i,d");
}

// ---------------------------------------------------------------------------
// 主循环
// ---------------------------------------------------------------------------
void loop() {
    unsigned long current_time = millis();

    // 每 50ms 执行一次控制循环
    if (current_time - last_control_time >= CONTROL_INTERVAL_MS) {
        last_control_time = current_time;
        timestamp_ms = current_time;

        // 1. 计算 PID 控制输出
        computePID();

        // 2. 更新仿真模型 (基于 PID 输出)
        updateSimulation();

        // 3. 上报数据给上位机 (Python)
        sendDataToSerial();
    }

    // 4. 监听并处理上位机指令
    processSerialCommand();
}

// ---------------------------------------------------------------------------
// 计算 PID 控制输出
// ---------------------------------------------------------------------------
void computePID() {
    // 计算误差
    float error = setpoint - current_temp;

    // 积分项 (带抗饱和限制)
    integral += error * (CONTROL_INTERVAL_MS / 1000.0f);

    // 限制积分项范围，防止积分饱和
    integral = constrain(integral, -100.0f, 100.0f);

    // 微分项
    float derivative = (error - prev_error) / (CONTROL_INTERVAL_MS / 1000.0f);

    // PID 输出计算
    float pid_output = kp * error + ki * integral + kd * derivative;

    // PWM 变化率限制 (防突变)
    float pwm_delta = pid_output - prev_pwm_output;
    if (fabs(pwm_delta) > PWM_CHANGE_MAX) {
        pid_output = prev_pwm_output + (pwm_delta > 0 ? PWM_CHANGE_MAX : -PWM_CHANGE_MAX);
    }

    // 限制 PWM 输出范围 (0-PWM_MAX)
    pwm_output = constrain(pid_output, 0.0f, PWM_MAX);
    prev_pwm_output = pwm_output;

    // 保存当前误差作为下一次微分的输入
    prev_error = error;
}

// ---------------------------------------------------------------------------
// 仿真模型：带惯性的加热系统
// ---------------------------------------------------------------------------
/**
 * 模型说明：
 * 一阶惯性热系统，模拟 PWM 驱动的加热器温度动态。
 *
 * 连续时间物理模型（牛顿加热/冷却定律）：
 *
 *   C * dT/dt = Q_in - Q_loss
 *
 *   其中：
 *     Q_in   = (pwm / PWM_MAX) * Q_max     — 加热功率，正比于 PWM 占空比
 *     Q_loss = k * (T - T_amb)             — 牛顿冷却，正比于与环境的温差
 *
 *   整理后：
 *     dT/dt  = (pwm / PWM_MAX) * α  -  (T - T_amb) * β
 *
 *   其中 α = Q_max / C（最大加热速率），β = k / C（散热时间常数的倒数）
 *
 * 离散化实现（前向欧拉，步长 Δt = CONTROL_INTERVAL_MS）：
 *
 *   heat_input = (pwm / PWM_MAX) * heating_factor   // α·Δt，归一化 PWM 驱动的温升
 *   heat_loss  = (T - T_amb)    * cooling_factor    // β·Δt，散热温降
 *   T[n+1]     = T[n] + heat_input - heat_loss
 *
 * 注：heating_factor / cooling_factor 已将 Δt 吸收在内，为无量纲步长增量系数。
 */
void updateSimulation() {
    const float heating_factor = 2.0f;   // 加热系数
    const float cooling_factor = 0.02f;  // 散热系数
    const float ambient_temp   = 20.0f;  // 环境温度

    // 计算温度变化
    float heat_input = (pwm_output / PWM_MAX) * heating_factor;  // 按实际量程归一化
    float heat_loss  = (current_temp - ambient_temp) * cooling_factor;

    // 更新温度
    current_temp += heat_input - heat_loss;
}

// ---------------------------------------------------------------------------
// 上报数据给上位机 (CSV 格式)
// ---------------------------------------------------------------------------
/**
 * 数据格式说明：
 * timestamp_ms, setpoint, input_value, pwm_output, error, kp, ki, kd
 *
 * 示例：
 * 5000,100.0,45.23,127.5,54.77,1.0,0.1,0.05
 */
void sendDataToSerial() {
    float error = setpoint - current_temp;

    Serial.print(timestamp_ms);
    Serial.print(",");
    Serial.print(setpoint, 2);
    Serial.print(",");
    Serial.print(current_temp, 2);
    Serial.print(",");
    Serial.print(pwm_output, 2);
    Serial.print(",");
    Serial.print(error, 2);
    Serial.print(",");
    Serial.print(kp, 3);
    Serial.print(",");
    Serial.print(ki, 3);
    Serial.print(",");
    Serial.println(kd, 3);
}
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

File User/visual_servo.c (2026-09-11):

#include "stm32f4xx.h"
#include "visual_servo.h"

/**
 * @brief  初始化视觉伺服句柄
 */
void VisualServo_Init(VisualServo_Handle *vs,
    int16_t target_tag_id, int16_t target_dist_cm,
    int16_t base_speed, float kp_lat, float ki_lat, float kd_lat,
    float kp_long, float ki_long, float kd_long, float dt)
{
    vs->target_tag_id      = target_tag_id;
    vs->target_distance_cm = target_dist_cm;
    vs->target_cx          = 160;       /* 320x240 图像的水平中心 */
    vs->base_speed_max     = base_speed;
    vs->turn_limit         = 200;       /* 差速限幅 (倒车时转弯不能太猛, 否则甩头丢码) */

    /* 横向 PID */
    vs->kp_lat = kp_lat;
    vs->ki_lat = ki_lat;
    vs->kd_lat = kd_lat;
    vs->integal_lat   = 0.0f;
    vs->last_err_lat  = 0.0f;
    vs->last_deriv_lat = 0.0f;

    /* 纵向 PID */
    vs->kp_long = kp_long;
    vs->ki_long = ki_long;
    vs->kd_long = kd_long;
    vs->integal_long   = 0.0f;
    vs->last_err_long  = 0.0f;
    vs->last_deriv_long = 0.0f;

    /* 通用 */
    vs->integral_sep_th = 60.0f;        /* 横向像素误差 > 60 时积分清零 */
    vs->dt = dt;

    /* 对准判定 */
    vs->aligned              = 0;
    vs->lost_cnt             = 0;
    vs->lost_threshold       = 20;      /* 20 帧 = 200ms 无标签判定丢失 */
    vs->aligned_threshold_x  = 10;      /* 横向 ±10 像素内视作对准 */
    vs->aligned_threshold_d  = 3;       /* 纵向 ±3cm 内视作对准 */
    vs->aligned_frames       = 0;
    vs->aligned_required     = 5;       /* 连续 5 帧对准判定稳定 */
}

/**
 * @brief  设置目标标签和距离
 */
void VisualServo_SetTarget(VisualServo_Handle *vs,
    int16_t tag_id, int16_t dist_cm)
{
    vs->target_tag_id      = tag_id;
    vs->target_distance_cm = dist_cm;
    vs->aligned            = 0;
    vs->aligned_frames     = 0;
}

/**
 * @brief  设置横向 PID 参数
 */
void VisualServo_SetLatPID(VisualServo_Handle *vs,
    float kp, float ki, float kd)
{
    vs->kp_lat = kp;
    vs->ki_lat = ki;
    vs->kd_lat = kd;
}

/**
 * @brief  设置纵向 PID 参数
 */
void VisualServo_SetLongPID(VisualServo_Handle *vs,
    float kp, float ki, float kd)
{
    vs->kp_long = kp;
    vs->ki_long = ki;
    vs->kd_long = kd;
}

/**
 * @brief  设置对准阈值
 */
void VisualServo_SetAlignThreshold(VisualServo_Handle *vs,
    int16_t x_px, int16_t d_cm, uint8_t frames)
{
    vs->aligned_threshold_x = x_px;
    vs->aligned_threshold_d = d_cm;
    vs->aligned_required    = frames;
}

/**
 * @brief  设置丢失阈值 (连续多少帧无标签判定丢失)
 */
void VisualServo_SetLostThreshold(VisualServo_Handle *vs,
    uint8_t threshold)
{
    vs->lost_threshold = threshold;
}

/**
 * @brief  重置 PID 积分和微分状态
 */
void VisualServo_Reset(VisualServo_Handle *vs)
{
    vs->integal_lat    = 0.0f;
    vs->last_err_lat   = 0.0f;
    vs->last_deriv_lat = 0.0f;
    vs->integal_long    = 0.0f;
    vs->last_err_long   = 0.0f;
    vs->last_deriv_long = 0.0f;
    vs->aligned         = 0;
    vs->aligned_frames  = 0;
    vs->lost_cnt        = 0;
}

/**
 * @brief  查询是否对准
 */
int VisualServo_IsAligned(const VisualServo_Handle *vs)
{
    return (vs->aligned != 0) ? 1 : 0;
}

/**
 * @brief  查询是否丢失标签
 */
int VisualServo_IsLost(const VisualServo_Handle *vs)
{
    return (vs->lost_cnt > vs->lost_threshold) ? 1 : 0;
}
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

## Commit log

2026-09-11 feat: 更新完成版 AGV 智能搬运机器人
    集成从车视觉对接、QR 触发 AI 抓取流程、OpenMV H7 Plus 脚本、PID 调参工具与挂钩 CAD 资源。
    [hook.dxf, hook.scad, hook.stl]
2026-09-11 docs: 完善项目 README
